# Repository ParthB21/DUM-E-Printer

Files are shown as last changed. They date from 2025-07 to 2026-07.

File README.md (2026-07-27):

# DUM-E Printer
## Demo at Open Sauce 2026
https://github.com/user-attachments/assets/50686566-a4c5-478c-9a64-cf04b380828b

## The Inspiration
We wanted to build our own 3D printer. Being die-hard Tony Stark fans, we decided to make a SCARA-style 3D printer. Introducing DUM-E Printer! It is a 5-axis robotic arm with with an extruder attached to the end to 3D print. Jokes aside, this project is really useful, becuase unlike the conventional fusion printers, the SCARA (Selective Compliance Assembly Robotic Arm) style printer is not limited by the volume of the printer bed. Morevoer, it's a lot more precise and offers greater flexibility because it has 5 axes of rotation and can directly print on top of any surface. Most importantly, SCARA-style printers are really expensive with almost no options for hobbyists. The only SCARA printers we could find were for industry and not amateurs, thus we took it as a challenge to make one and possess this cool Tony Stark-style tech.

## The Struggle
This was an extremely challenging process partly because there is no tutorial to make a SCARA 3D printer. We used a bunch of tutorials as references [in-text citation] to make a robotic arm and then figured out a way to add the 3D printer extruder to it. It's safe to say that in the past 3 weeks, 2 amateurs have become Onshape pros.

## Technical Features
We plan on using an affordable prebuilt extruder from Creality to do the actual printing. The Marlin firmware is run by an Mks Robin Nano Motherboard. For the printer's display, we have a TS35 Touchscreen. DUM-E Printer uses 5 Stepper Motors to achieve motion. There are multiple bearings in the joints to facilitate rotation.

## CAD Model
Isometric view of the assembled printer:



Top view of the assembled printer:



Front view of the assembled printer:



Side view of the assembled printer:



Exploded Diagram of the printer (to view the motors and the bearings):





Note: The blue parts are the ones that need to be 3D printed and the grey ones are the makeshift components

## Wiring Diagram


## BOM
Note: We used Amazon for some of the parts because they were either the same price or cheaper than Aliexpress. Amazon's delivery is much faster than Aliexpress so we preferred to use it if the price is same or less. All the costs beyond $350 USD will be covered by Sujay and Parth.
| Part Name | Quantity | CAD Unit Price | USD Unit Price | USD Total Cost | Link |
|---|---|---|---|---|---|
| MEISHILE 24V 25A 600W Switching Power Supply | 1 | $40.99 | $29.92 | $29.92 | [Link](https://www.amazon.ca/MEISHILE-Switching-Transformer-Converter-Amplifier/dp/B0C299DG1H) |
| Creality Ender 3 Direct Drive Extruder Upgrade Kit | 1 | $41.39 | $30.21 | $30.21 | [Link](https://www.amazon.ca/Official-Creality-Extruder-Compatible-3D/dp/B0C2CH7P54) |
| Mks Robin Nano V3.1 Eagle 32bit Control Panel TMC2209 with Screen | 1 | $52.99 | $38.68 | $38.68 | [Link](https://www.aliexpress.com/item/1005008555474559.html) |
| 22 AWG 10 m shielded wire | 1 | $9.58 | $6.99 | $6.99 | [Link](https://www.aliexpress.com/item/4000850790419.html) |
| 22 AWG 20 m silicone wire | 1 | $8.19 | $5.98 | $5.98 | [Link](https://www.aliexpress.com/item/1005006250522147.html) |
| Crimper Cable Cutter Adjustable Automatic Wire Stripper | 1 | $8.39 | $6.12 | $6.12 | [Link](https://www.aliexpress.com/item/1005007148577702.html) |
| 10PCS PCB Terminal Block Connector | 1 | $1.61 | $1.18 | $1.18 | [Link](https://www.aliexpress.com/item/1005006642865467.html) |
| 200Pcs/Box 2.54mm Pitch JST SM/Dupont Jumper Wire Connector Kit | 1 | $7.39 | $5.39 | $5.39 | [Link](https://www.aliexpress.com/item/1005003140788241.html) |
| M3 M4 M5 Bolt kit | 1 | $23.79 | $17.37 | $17.37 | [Link](https://www.aliexpress.com/item/1005008261719970.html) |
| 4x10x4 mm Bearings Set of 10 | 1 | $5.79 | $4.23 | $4.23 | [Link](https://www.aliexpress.com/item/1005007668446060.html) |
| 18x30x7 mm Bearings Set of 10 | 1 | $11.89 | $8.68 | $8.68 | [Link](https://www.aliexpress.com/item/1005009272681515.html) |
| Bore with teeth set of 6 | 1 | $8.51 | $6.21 | $6.21 | [Link](https://www.aliexpress.com/item/1005007557987612.html) |
| Belt 6mm 5m open | 1 | $5.32 | $3.88 | $3.88 | [Link](https://www.aliexpress.com/item/1005007542222728.html) |
| Bore without teeth set of 6 | 1 | $8.60 | $6.28 | $6.28 | [Link](https://www.aliexpress.com/item/1005007557987612.html) |
| Digital Caliper | 1 | $7.25 | $5.29 | $5.29 | [Link](https://www.aliexpress.com/item/1005003772701402.html) |
| Nema23 1.5 Nm stepper motors | 2 | $41.38 | $30.21 | $60.41 | [Link](https://www.aliexpress.com/item/1005007638437234.html) |
| 14:1 Gearbox + Stepper motor | 1 | $34.58 | $25.24 | $25.24 | [Link](https://www.aliexpress.com/item/1005007401751232.html) |
| 19:1 Gearbox + Stepper motor | 1 | $34.58 | $25.24 | $25.24 | [Link](https://www.aliexpress.com/item/1005007401751232.html) |
| 51:1 Gearbox + Stepper motor | 1 | $35.58 | $25.97 | $25.97 | [Link](https://www.aliexpress.com/item/1005007401751232.html) |

Total cost after taxes (in USD) = $354.03

## Citations
https://roboticworx.io/blogs/projects/build-a-5-axis-industrial-grade-robotic-arm-that-learns-how-to
https://www.drdflo.com/pages/Guides/How-to-Build-a-3D-Printer/FFF.html
https://grabcad.com/library/nema-17-40mm-stepper-motor-1
https://www.thingiverse.com/thing:2703913#google_vignette
https://ceadgroup.com/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
https://www.3dwasp.com/en/extruders-for-robotic-arm/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
https://www.youtube.com/watch?v=5toNqaGsGYs
https://www.youtube.com/watch?v=OiQKw0lZ5Rw

## Quick Notes from Authors
1. We made makeshift files and got some pre-made files for motors, gearboxes, etc. that are not going to be 3D printed as placeholders to make sure all of our CAD files are formatted properly
2. We found a template for the Marlin firmware that corresponds to the kinematics of a SCARA 3D Printer, so we plan to use that as a template and configure it based on our arm as we build it physically. 
3. Full Firmware is in the firmware branch of the repository
   - The files that are changed from the original Marlin 2.1 firmware (so far) are: Configuration.h, Configuration_adv.h, scara.h, scara.cpp, motion.cpp, servo.cpp
   - These files were modified with some help from ChatGPT and will be debugged while building and testing with hardware!

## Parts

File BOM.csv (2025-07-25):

Part Name | Quantity | CAD Unit Price | USD Unit Price | USD Total Cost | Links
MEISHILE 24V 25A 600W Switching Power Supply | 1 | $40.99 | $29.92 | $29.92 | https://www.amazon.ca/MEISHILE-Switching-Transformer-Converter-Amplifier/dp/B0C299DG1H
Creality Ender 3 Direct Drive Extruder Upgrade Kit | 1 | $41.39 | $30.21 | $30.21 | https://www.amazon.ca/Official-Creality-Extruder-Compatible-3D/dp/B0C2CH7P54
Mks Robin Nano V3.1 Eagle 32bit Control Panel TMC2209 with Screen | 1 | $52.99 | $38.68 | $38.68 | https://www.aliexpress.com/item/1005008555474559.html?mp=1
22 AWG 10 m shielded wire | 1 | $9.58 | $6.99 | $6.99 | https://www.aliexpress.com/item/4000850790419.html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
22 AWG 20 m silicone wire | 1 | $8.19 | $5.98 | $5.98 | https://www.aliexpress.com/item/1005006250522147.html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
Crimper Cable Cutter Adjustable Automatic Wire Stripper | 1 | $8.39 | $6.12 | $6.12 | https://www.aliexpress.com/item/1005007148577702.html?mp=1
10PCS PCB Terminal Block Connector | 1 | $1.61 | $1.18 | $1.18 | https://www.aliexpress.com/item/1005006642865467.html?mp=1
200Pcs/Box 2.54mm Pitch JST SM/Dupont Jumper Wire Connector Kit | 1 | $7.39 | $5.39 | $5.39 | https://www.aliexpress.com/item/1005003140788241.html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
M3 M4 M5 Bolt kit | 1 | $23.79 | $17.37 | $17.37 | https://www.aliexpress.com/item/1005008261719970.html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
4x10x4 mm Bearings Set of 10 | 1 | $5.79 | $4.23 | $4.23 | https://www.aliexpress.com/item/1005007668446060.html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
18x30x7 mm Bearings Set of 10 | 1 | $11.89 | $8.68 | $8.68 | https://www.aliexpress.com/item/1005009272681515.html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
Bore with teeth set of 6 | 1 | $8.51 | $6.21 | $6.21 | https://www.aliexpress.com/item/1005007557987612.html?mp=1
Belt 6mm 5m open | 1 | $5.32 | $3.88 | $3.88 | https://www.aliexpress.com/item/1005007542222728.html?mp=1
Bore without teeth set of 6 | 1 | $8.60 | $6.28 | $6.28 | https://www.aliexpress.com/item/1005007557987612.html?mp=1
Digital Caliper | 1 | $7.25 | $5.29 | $5.29 | https://www.aliexpress.com/item/1005003772701402.html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
Nema23 1.5 Nm stepper motors | 2 | $41.38 | $30.21 | $60.41 | https://www.aliexpress.com/item/1005007638437234.html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
14:1 Gearbox + Stepper motor | 1 | $34.58 | $25.24 | $25.24 | https://www.aliexpress.com/item/1005007401751232.html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
19:1 Gearbox + Stepper motor | 1 | $34.58 | $25.24 | $25.24 | https://www.aliexpress.com/item/1005007401751232.html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
51:1 Gearbox + Stepper motor | 1 | $35.58 | $25.97 | $25.97 | https://www.aliexpress.com/item/1005007401751232.html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
 |  | $387.80 | $283.09 | $313.30
 |  |  | Shipping USD | $0.00
 |  |  | Total USD (including tax) | $354.03

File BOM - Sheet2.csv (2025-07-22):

Part Name | Quantity | CAD Unit Price | USD Unit Price | USD Total Cost | Links | Notes
MEISHILE 24V 25A 600W Switching Power Supply | 1 | $42.99 | $31.38 | $31.38 | https://www.amazon.ca/MEISHILE-Switching-Transformer-Converter-Amplifier/dp/B0C299DG1H
ELEGOO PLA Filament 1.75mm Black 1KG | 1 | $23.99 | $17.51 | $17.51 | https://www.amazon.ca/ELEGOO-Filament-Dimensional-Accuracy-Compatible/dp/B0BM4F65SL
Creality Ender 3 Direct Drive Extruder Upgrade Kit | 1 | $41.39 | $30.21 | $30.21 | https://www.amazon.ca/Official-Creality-Extruder-Compatible-3D/dp/B0C2CH7P54
Mks Robin Nano V3.1 Eagle 32bit Control Panel TMC2209 with Screen | 1 | $52.99 | $38.68 | $38.68 | https://www.aliexpress.com/item/1005008555474559.html?mp=1
Heat Resistant Soft Silicone Wire 5 Colors in A Box Kit 30AWG 100 meters | 1 | $14.68 | $10.72 | $10.72 | https://www.aliexpress.com/item/1005006350734418.html?mp=1
Crimper Cable Cutter Adjustable Automatic Wire Stripper | 1 | $8.39 | $6.12 | $6.12 | https://www.aliexpress.com/item/1005007148577702.html?mp=1
10PCS PCB Terminal Block Connector | 1 | $1.61 | $1.18 | $1.18 | https://www.aliexpress.com/item/1005006642865467.html?mp=1
200Pcs/Box 2.54mm Pitch JST SM/Dupont Jumper Wire Connector Kit | 1 | $7.39 | $5.39 | $5.39 | https://www.aliexpress.com/item/1005003140788241.html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
M4 Bolt Kit | 1 | $8.59 | $6.27 | $6.27 | https://www.aliexpress.com/item/1005008261719970.html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
M3 Bolt Kit | 1 | $8.80 | $6.42 | $6.42 | https://www.aliexpress.com/item/1005007552265164.html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
4x10x4 mm Bearings Set of 10 | 1 | $5.79 | $4.23 | $4.23 | https://www.aliexpress.com/item/1005007668446060.html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
18x30x7 mm Bearings Set of 10 | 1 | $11.89 | $8.68 | $8.68 | https://www.aliexpress.com/item/1005009272681515.html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 | This link is for 5*10*4 mm bearings, should I change it to 4*10*4
Bore with teeth set of 6 | 1 | $8.51 | $6.21 | $6.21 | https://www.aliexpress.com/item/1005007557987612.html?mp=1
Belt 6mm 5m open | 1 | $5.32 | $3.88 | $3.88 | https://www.aliexpress.com/item/1005007542222728.html?mp=1 | The link is wrong, this is not a belt
Bore without teeth set of 6 | 1 | $8.60 | $6.28 | $6.28 | https://www.aliexpress.com/item/1005007557987612.html?mp=1
Digital Caliper | 1 | $7.25 | $5.29 | $5.29 | https://www.aliexpress.com/item/1005003772701402.html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
5.18:1 Gearbox + Stepper motor | 2 | $33.58 | $24.51 | $49.03 | https://www.aliexpress.com/item/1005007401751232.html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
14:1 Gearbox + Stepper motor | 1 | $34.58 | $25.24 | $25.24 | https://www.aliexpress.com/item/1005007401751232.html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
19:1 Gearbox + Stepper motor | 1 | $34.58 | $25.24 | $25.24 | https://www.aliexpress.com/item/1005007401751232.html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
51:1 Gearbox + Stepper motor | 1 | $35.58 | $25.97 | $25.97 | https://www.aliexpress.com/item/1005007401751232.html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
 |  | $396.50 | $289.45 | $313.96
 |  |  | Shipping USD | $0.00
 |  |  | Total USD | $313.96

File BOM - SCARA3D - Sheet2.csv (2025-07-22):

Part Name | Quantity | CAD Unit Price | USD Unit Price | USD Total Cost | Links | Notes
MEISHILE 24V 25A 600W Switching Power Supply | 1 | $42.99 | $31.38 | $31.38 | MEISHILE 24V 25A 600W Switching Power Supply Adapter AC to DC Transformer Converter for LED Driver Strip Light Lamp, Amplifier, Machine, 120V 110V to 24Volt 3A 4A 5A 8A 10A 15A 20Amp : Amazon.ca: Tools & Home Improvement
ELEGOO PLA Filament 1.75mm Black 1KG | 1 | $23.99 | $17.51 | $17.51 | ELEGOO PLA Filament 1.75mm Black 1KG,3D Printer Filament Dimensional Accuracy +/- 0.02mm,1kg Cardboard Spool(2.2lbs) 3D Printing Filament Fits for Most FDM 3D Printers : Amazon.ca: Industrial & Scientific
Creality Ender 3 Direct Drive Extruder Upgrade Kit | 1 | $41.39 | $30.21 | $30.21 | Official Creality Ender 3 Direct Drive Extruder Upgrade Kit with 42-40 Stepper Motor Hotend Kit, Support Flexible TPU Filament, Compatible with Ender 3 Pro/Ender 3 V2 3D Printer : Amazon.ca: Industrial & Scientific
Mks Robin Nano V3.1 Eagle 32bit Control Panel TMC2209 with Screen | 1 | $52.99 | $38.68 | $38.68 | Makerbase Mks Robin Nano V3.1 Eagle 32bit Control Panel TMC2209 Motor Drive WIFI 3D Touch Screen 3D Printer Parts Motherboard - AliExpress
Heat Resistant Soft Silicone Wire 5 Colors in A Box Kit 30AWG 100 meters | 1 | $14.68 | $10.72 | $10.72 | Super Soft Copper Wire Box (5 Colors Mix Kit) Heat Resistant Flexible Silicone 30/28/26/24/22/20AWG Electric Tinned Copper Cable - AliExpress |  | Shipping USD | $0.00
Crimper Cable Cutter Adjustable Automatic Wire Stripper | 1 | $8.39 | $6.12 | $6.12 | Crimper Cable Cutter Adjustable Automatic Wire Stripper Multifunctional Stripping Crimping Pliers Terminal Hand Tool - AliExpress |  | Total USD | $313.96
10PCS PCB Terminal Block Connector | 1 | $1.61 | $1.18 | $1.18 | 10/50PCS PCB Terminal Block Connector Pitch 5.0mm KF301 Straight Pin 2P 3P Screw PCB Terminal Blocks Connector Assortment Kit - AliExpress 13
200Pcs/Box 2.54mm Pitch JST SM/Dupont Jumper Wire Connector Kit | 1 | $7.39 | $5.39 | $5.39 | 200Pcs/Box 2.54mm Pitch JST SM/Dupont Jumper Wire Connector Kit 2/3/4/5Pin Male/Female Housing Pin Header Crimp Terminal Adapter - AliExpress
M4 Bolt Kit | 1 | $8.59 | $6.27 | $6.27 | M4 M5 M6 Metric Bolt Kit Stainless Steel Assortment Set with Hex Head Bolts Nuts Flat & Lock Washer for DIY Home Industrial Use - AliExpress
M3 Bolt Kit | 1 | $8.80 | $6.42 | $6.42 | 320/640pcs M3 Screw Stainless Steel Hexagon Hex Socket Screws Bolt Nuts Set Round Flat Cap Head Bolt Washer Assortment Kit - AliExpress
4x10x4 mm Bearings Set of 10 | 1 | $5.79 | $4.23 | $4.23 | 10/50pcs Small Bearings 2mm 3mm 4mm 5mm 6mm 7mm 8mm 9mm 10mm Bore 3x7x3 5x10x4 5x11x4 8x22x7 10x15x4 mm Miniature Bearing - AliExpress
18x30x7 mm Bearings Set of 10 | 1 | $11.89 | $8.68 | $8.68 | 10pcs 16100 12268 15267 15268 16287 163010 18287 18307 20307 24377 25376 2RS RS Bearings Rubber Sealed Bicycle Ball Bearing - AliExpress | This link is for 5*10*4 mm bearings, should I change it to 4*10*4
Bore with teeth set of 6 | 1 | $8.51 | $6.21 | $6.21 | 2/4/6pcs GT2 Idler Timing Pulley 16/20 Tooth Wheel Bore 3/5mm Aluminium Gear Teeth Width 6/10mm For Ender 3 CR10 Printer Reprap - AliExpress
Belt 6mm 5m open | 1 | $5.32 | $3.88 | $3.88 | 5/10M GT2 Belt PU Steel Wire Timing Pulley GT2-6mm Open Synchronous Rubber Belts Width 6mm for DIY CNC 3D Printer Parts - AliExpress | The link is wrong, this is not a belt
Bore without teeth set of 6 | 1 | $8.60 | $6.28 | $6.28 | 2/4/6pcs GT2 Idler Timing Pulley 16/20 Tooth Wheel Bore 3/5mm Aluminium Gear Teeth Width 6/10mm For Ender 3 CR10 Printer Reprap - AliExpress
Digital Caliper | 1 | $7.25 | $5.29 | $5.29 | 150mm 100mm Electronic Digital Caliper Carbon Fiber Dial Vernier Caliper Gauge Micrometer Measuring Tool Digital Ruler - AliExpress
5.18:1 Gearbox + Stepper motor | 2 | $33.58 | $24.51 | $49.03 | 1Pc 42BYG stepper motor 40mm body length with 3.71:1 -139:1 ratio NEMA17 planetary gear stepping motor with gearbox - AliExpress
14:1 Gearbox + Stepper motor | 1 | $34.58 | $25.24 | $25.24 | 1Pc 42BYG stepper motor 40mm body length with 3.71:1 -139:1 ratio NEMA17 planetary gear stepping motor with gearbox - AliExpress
19:1 Gearbox + Stepper motor | 1 | $34.58 | $25.24 | $25.24 | 1Pc 42BYG stepper motor 40mm body length with 3.71:1 -139:1 ratio NEMA17 planetary gear stepping motor with gearbox - AliExpress
51:1 Gearbox + Stepper motor | 1 | $35.58 | $25.97 | $25.97 | 1Pc 42BYG stepper motor 40mm body length with 3.71:1 -139:1 ratio NEMA17 planetary gear stepping motor with gearbox - AliExpress
 |  |  | $0.00 | $0.00
 |  | $396.50 | $289.45 | $313.96

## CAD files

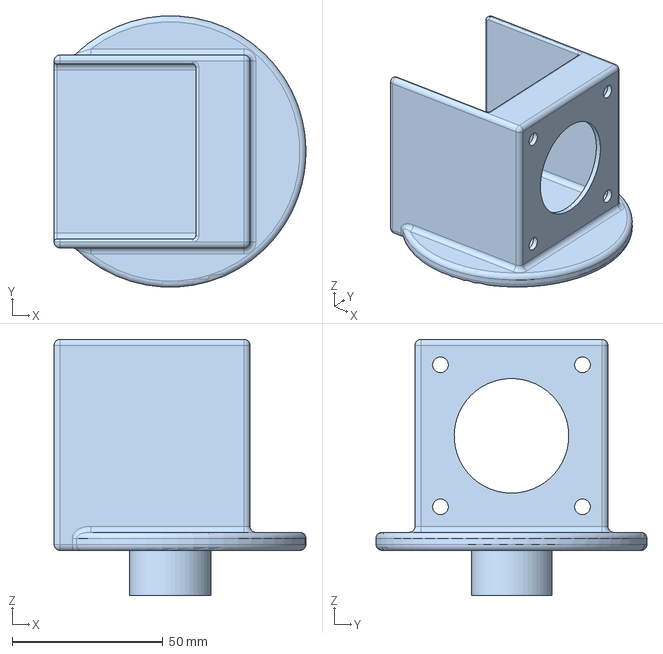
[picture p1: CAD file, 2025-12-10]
CAD/Wrist Pitch mount.step
83.5 x 89.9 x 85.0 mm

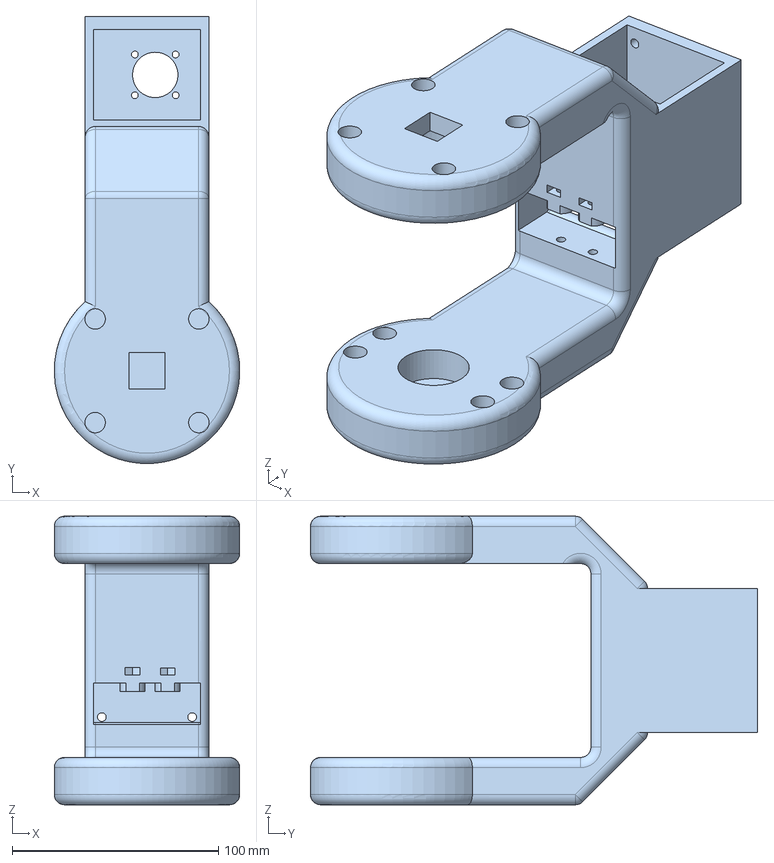
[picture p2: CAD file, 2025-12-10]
CAD/J1.step
90.0 x 216.9 x 140.0 mm

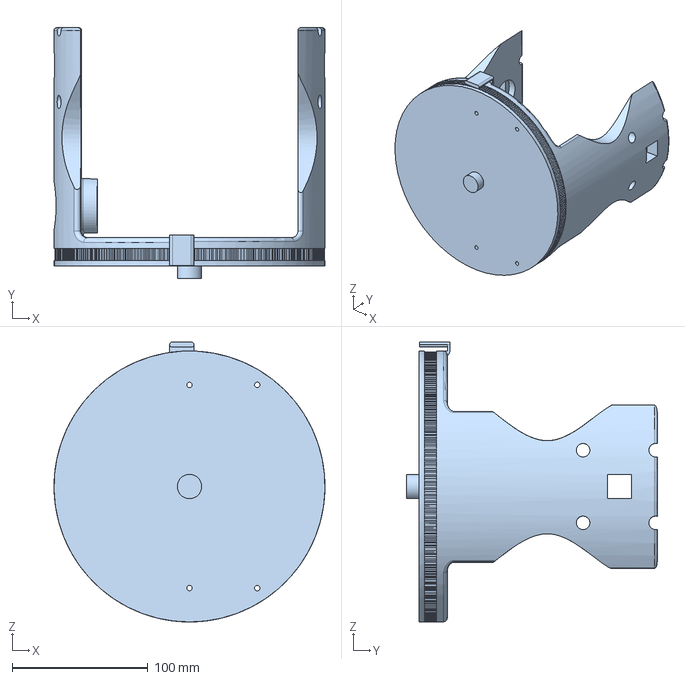
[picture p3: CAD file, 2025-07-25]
CAD/Base.step
200.0 x 185.0 x 206.6 mm

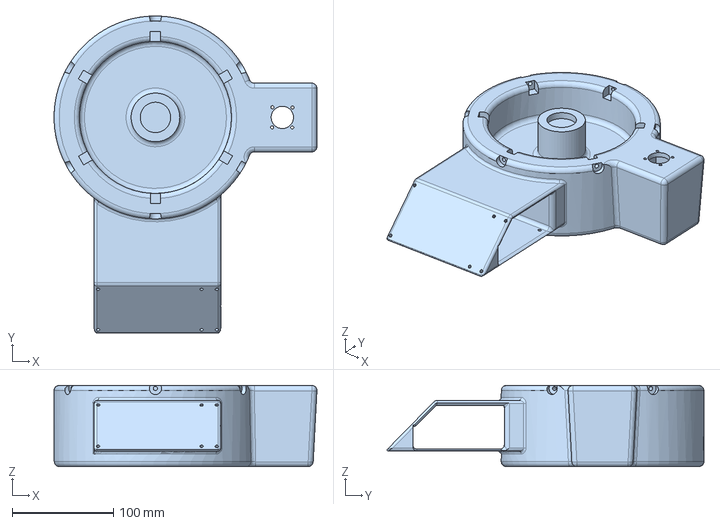
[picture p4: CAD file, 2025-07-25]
CAD/Base Plate.step
259.3 x 312.6 x 80.0 mm

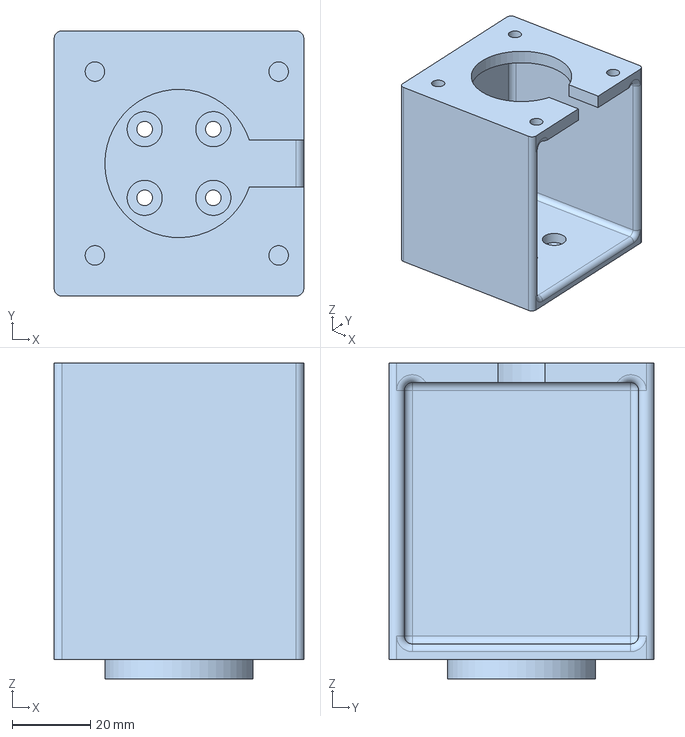
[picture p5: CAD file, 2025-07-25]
CAD/Wrist Roll.step
64.0 x 68.0 x 81.0 mm

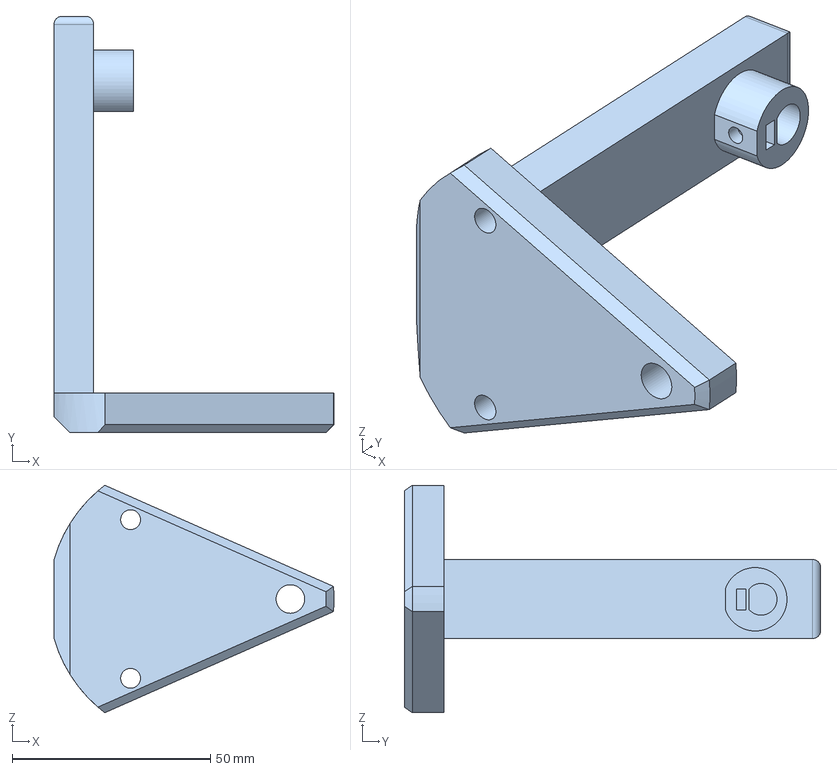
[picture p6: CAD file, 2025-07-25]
CAD/Wrist Pitch End.step
70.6 x 105.0 x 57.4 mm

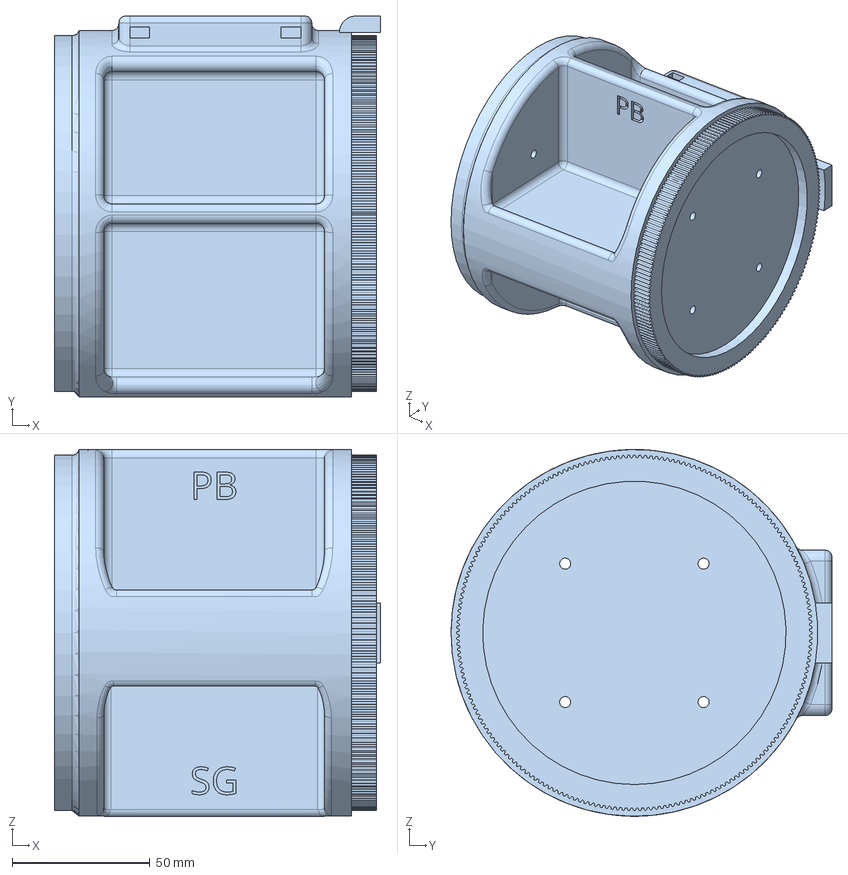
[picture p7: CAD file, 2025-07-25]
CAD/J1 Base.step
118.4 x 138.2 x 133.1 mm

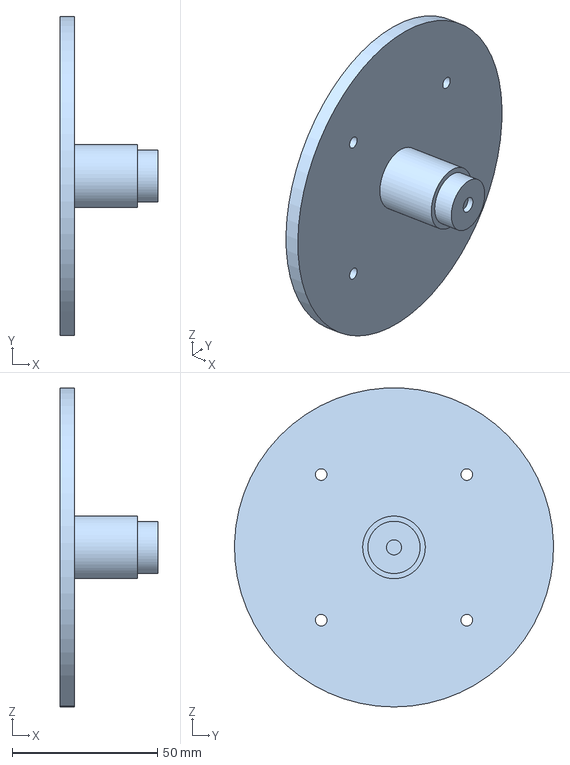
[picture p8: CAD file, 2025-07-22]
CAD/J1 Base Mount.step
33.7 x 110.0 x 109.9 mm

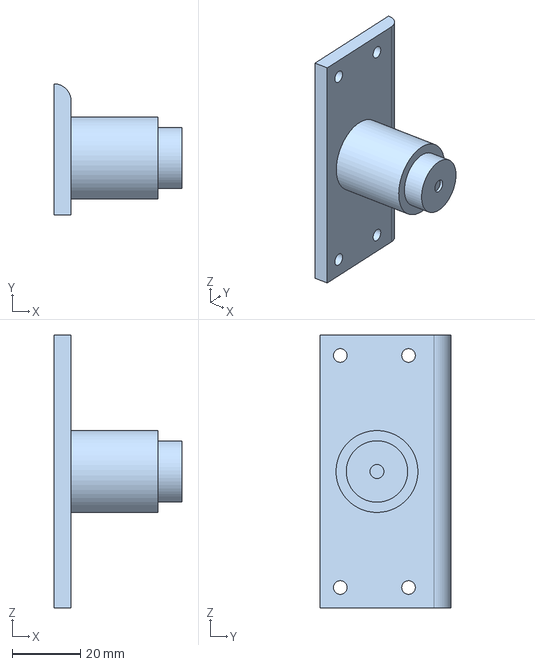
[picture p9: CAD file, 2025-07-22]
CAD/J2 Mount - no teeth.step
37.5 x 38.5 x 80.0 mm

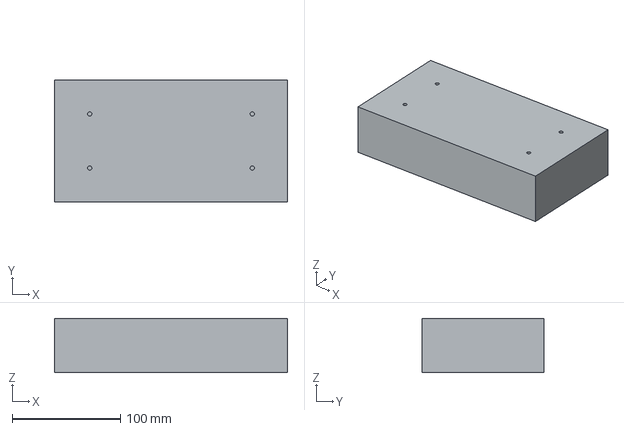
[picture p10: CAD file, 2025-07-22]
CAD/Makeshift power supply.step
215.0 x 112.5 x 50.0 mm

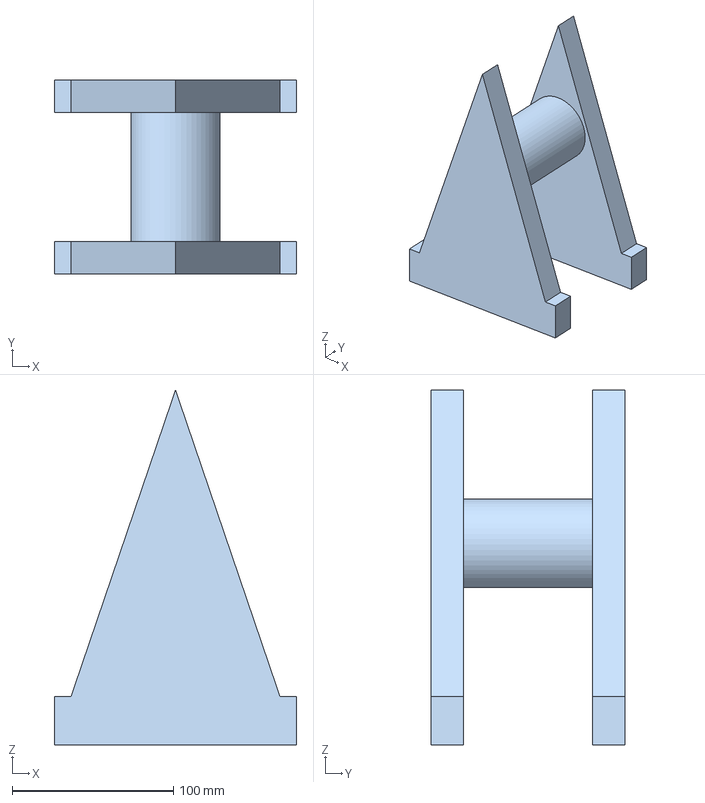
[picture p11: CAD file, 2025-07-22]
CAD/Spool stand.step
150.0 x 120.0 x 220.0 mm

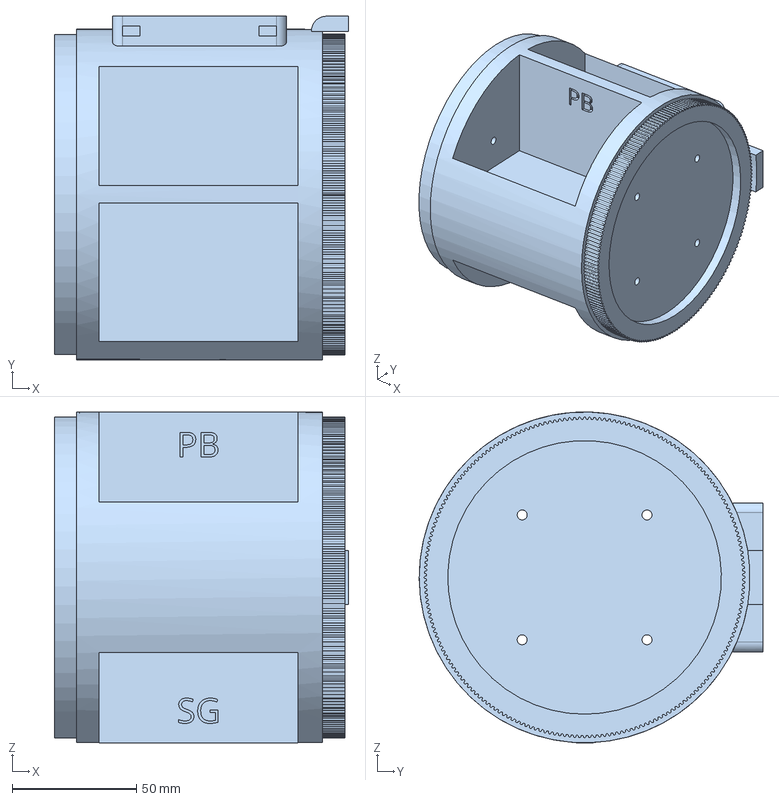
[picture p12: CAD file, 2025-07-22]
CAD/J1 Base New.step
118.4 x 138.2 x 133.1 mm

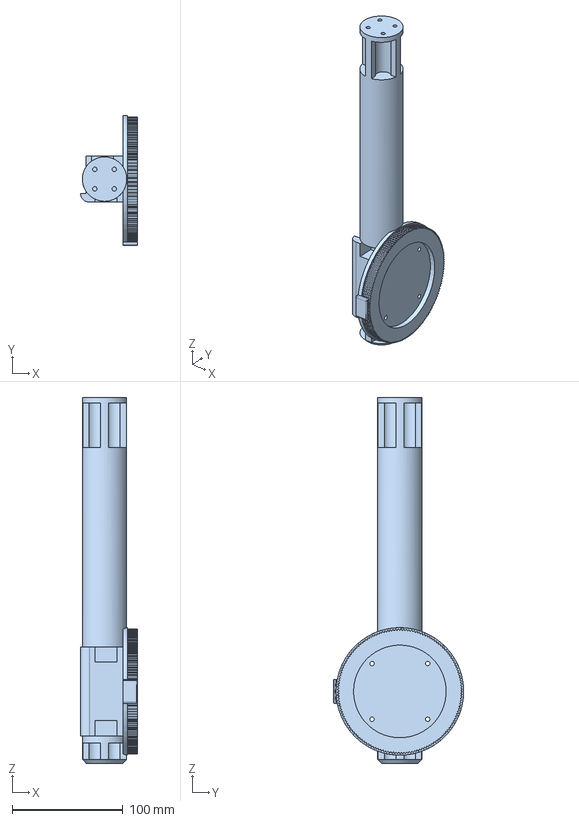
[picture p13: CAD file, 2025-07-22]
CAD/J2.step
51.5 x 117.5 x 330.0 mm

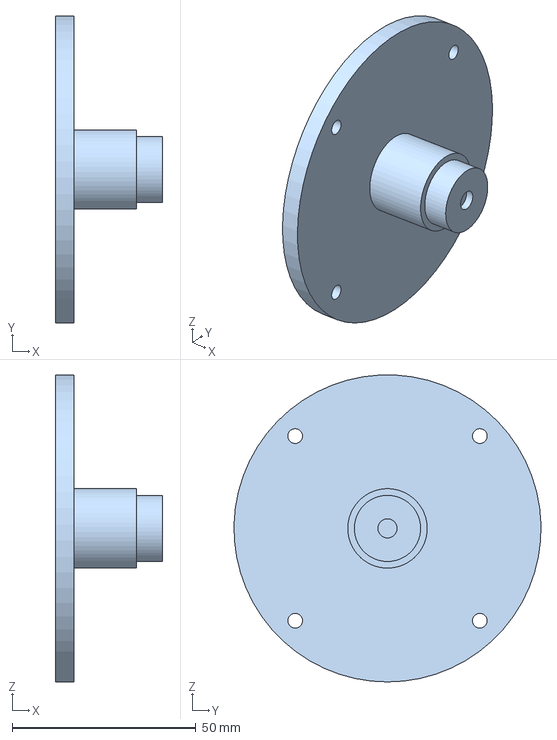
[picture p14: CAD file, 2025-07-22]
CAD/J2 Mount.step
29.0 x 83.5 x 83.4 mm

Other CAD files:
CAD/Wrist Pitch Motor Horn.step
CAD/Extruder.step

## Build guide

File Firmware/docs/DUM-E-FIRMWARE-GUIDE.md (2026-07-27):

# DUM-E — Step-by-step bring-up

Follow the steps **in order**. Do not skip ahead to heating or homing until the earlier steps pass.

**What this robot can do right now:** move four joints (yaw, shoulder pitch, wrist pitch, wrist roll) and run the extruder. It is **not** a normal Cartesian printer yet. When you send `G1 X10`, that means “move shoulder yaw by about 10 degrees,” **not** “move 10 mm in X.”

---

## Quick map (keep this nearby)

| Motor plug on board | What it moves | Command letter |
| --- | --- | --- |
| **X** | Shoulder yaw | `X` |
| **Y** | Wrist pitch | `Y` |
| **Z** (Z0 and Z1 = same motor) | Shoulder pitch | `Z` |
| **E0** | Wrist roll | `A` |
| **E1** | Filament extruder | `E` |

---

# STEP 1 — Safety before anything moves

1. Put the arm somewhere it cannot hit the table or itself.
2. Keep your hand on the **24 V power switch** so you can cut power instantly.
3. Prefer the arm **supported** or joints free for the first tiny moves.
4. Do **not** heat the hotend in this step.

**You’re done with Step 1 when:** you can kill power in one second.

---

# STEP 2 — Build the firmware (if you haven’t)

1. Open the folder `Marlin-2.1.2.6` in Cursor / VS Code.
2. Open **Marlin Auto Build** (or PlatformIO).
3. Click **Build** on environment `**mks_robin_nano_v3_1`**.
4. Wait until it says **SUCCESS** (warnings are OK).

**You should see:** green success, file created under  
`.pio/build/mks_robin_nano_v3_1/Robin_nano_v3.bin`

**If it fails:** copy the red errors and ask for help (don’t continue).

**You’re done with Step 2 when:** the `.bin` file exists.

---

# STEP 3 — Put firmware on SD or USB stick

1. Format the SD card or USB stick as **FAT32**.
2. Open the folder:
  `Marlin-2.1.2.6/.pio/build/mks_robin_nano_v3_1/`
3. Copy **both** of these to the **root** of the stick (not in a subfolder):
  - `Robin_nano_v3.bin` (exact name)
  - the whole folder named `assets`
4. Eject the stick safely from the PC.

**You’re done with Step 3 when:** stick root contains `Robin_nano_v3.bin` and `assets/`.

---

# STEP 4 — Flash the board

1. Insert the SD card **or** plug the USB stick into the board’s **USB-A host** port (big flat USB, not the tiny USB-to-PC).
2. Connect the **24 V power supply** and turn it on.
3. Watch the TS35 screen.

**You should see:**

1. An update / progress screen, then
2. The board restarts into the Marlin UI.

**Also check the stick afterward:** `Robin_nano_v3.bin` may be renamed to something like `Robin_nano_v3.CUR` — that means flash worked.

**If the screen stays blank:**

- Confirm `assets` was copied
- Confirm 24 V is on
- Reseat the TS35 cable
- Try a different FAT32 SD card

**You’re done with Step 4 when:** the touchscreen shows a normal Marlin / MKS main screen and the machine name is **DUM-E** (or similar).

---

# STEP 5 — Open serial on the PC (PlatformIO)

This is how you type test commands.

1. Leave **24 V on**.
2. Plug the board’s **small USB** (to PC) into your computer.
3. In Cursor / VS Code with the Marlin project open:
  - PlatformIO sidebar → **PROJECT TASKS** → `mks_robin_nano_v3_1` → **General** → **Monitor**  
  - or click the PlatformIO **serial plug** icon
4. Baud rate is already **115200**.

**You should see:** a terminal window that connects to a COM port (may show `echo:` or be quiet until you type).

**If it says port busy / can’t open:**

- Close Pronterface or any other serial program
- Unplug/replug USB
- Try again

**You’re done with Step 5 when:** the serial monitor stays open without errors.

---

# STEP 6 — Smoke test (no motor moves yet)

In the serial monitor, type each line and press Enter.

### 6.1 — Is firmware alive?

Type:

```text
M115
```

**You should see:** text mentioning Marlin and the board.

### 6.2 — Are temperatures sane?

Type:

```text
M105
```

**You should see:** a hotend temperature near room temperature (e.g. 20–30 °C).  
**Do not** send heat commands yet.

### 6.3 — Can the drivers talk over UART?

Type:

```text
M122
```

**You should see:** driver reports for the axes.  
**Bad sign:** lines like `Unable to communicate` for X/Y/Z/E — stop and fix wiring/config before moving motors.

**You’re done with Step 6 when:** `M115`, `M105`, and `M122` all look healthy.

---

# STEP 7 — Tiny joint moves (direction test)

Still in serial monitor. Move **one joint at a time**. Watch the robot. Be ready to kill power.

First put Marlin in relative mode:

```text
G91
```

### 7.1 — Shoulder yaw (plug X)

```text
G1 X5 F20
```

**You should see:** shoulder yaw move a little.

- Wrong way? Note it as “X inverted” (we’ll fix after).
- No move / skipping? Kill power; note which motor.

### 7.2 — Wrist pitch (plug Y)

```text
G1 Y5 F20
```

### 7.3 — Shoulder pitch (plug Z)

```text
G1 Z5 F20
```

### 7.4 — Wrist roll (plug E0, commanded as A)

```text
G1 A5 F20
```

### 7.5 — Fix wrong directions (if needed)

If a joint moved the wrong way:

1. Open `Marlin/Configuration.h`
2. Find `INVERT_X_DIR`, `INVERT_Y_DIR`, `INVERT_Z_DIR`, `INVERT_I_DIR` (I = wrist roll / A)
3. Change `false` ↔ `true` for that axis only
4. Rebuild (Step 2), reflash (Steps 3–4), retest that one joint

**You’re done with Step 7 when:** each joint moves in a direction you agree is “positive.”

### If motors do NOT move (do this checklist)

Send these **one line at a time** and watch both the reply **and** the motors:

```text
M115
M122
M211 S0
M17
G92 X0 Y0 Z0 A0
G91
G1 X30 F30
```

What each does:

| Command | Purpose |
| --- | --- |
| `M122` | Confirms TMC drivers answer (if “Unable to communicate”, motors won’t work until UART/drivers are fixed) |
| `M211 S0` | Turn **off** soft endstops (they can silently block moves) |
| `M17` | **Enable** steppers (motors should feel locked / harder to turn by hand) |
| `G92 ...` | Set current joint angles to 0 so limits don’t block you |
| `G1 X30 F30` | Bigger, easier-to-see yaw move |

**Check with your hand (power on, after `M17`):**

1. Try to twist the **X** motor shaft / coupling gently.
2. If it feels **free / floppy** → steppers are not enabled or not powered.
3. If it feels **locked** but still doesn’t move on `G1` → note the serial reply and tell me what it said.

**Also confirm physically:**

- 24 V PSU is on (USB alone is not enough for motors)
- Motor plugs are fully seated in **X / Y / Z / E0 / E1**
- You’re testing the motor that matches the command (`X` = shoulder yaw plug)

**Common serial replies:**

| You see | Meaning |
| --- | --- |
| `ok` and motor locked but no motion | Tell me; may be current / wiring / wrong plug |
| `echo:Unknown command: "G1 A..."` | Use `G1 I5 F20` instead, or rebuild with I-axis enabled |
| Endstop / homing / “must home” style message | Paste the exact text |
| `Unable to communicate` in `M122` | Fix TMC UART first — motion won’t work |

**Reset settings if an old EEPROM is fighting you:**

```text
M502
M500
M17
G92 X0 Y0 Z0 A0
G91
G1 X30 F30
```

---

# STEP 8 — Calibrate steps (angle accuracy)

You don’t need exact belt ratios. Measure instead.

Example for **X** (do the same idea for Y, Z, A):

1. Mark the joint with tape/pen so you can see rotation.
2. Send:

```text
G91
G1 X90 F30
```

1. Measure how many degrees it **actually** moved (protractor / careful estimate is fine for now).
2. Compute:

`new_steps = old_steps × (90 / measured_degrees)`

Starting values already in firmware:

- X ≈ 124.44  
- Y ≈ 8.89  
- Z ≈ 453.33  
- A ≈ 8.89

1. Apply temporarily over serial (example if new X steps were 200):

```text
M92 X200
M500
```

Or edit `DEFAULT_AXIS_STEPS_PER_UNIT` in `Configuration.h` and rebuild later.

**You’re done with Step 8 when:** commanding ~90° on each joint gets roughly 90° of real motion.

---

# STEP 9 — Wire the 4 endstops (later; skip until motors feel good)

Do this **after** Steps 6–8 feel safe.

### 9.1 — Remove DIAG jumpers

On the Robin Nano, **remove the DIAG jumpers** (needed because you use real endstops, not sensorless).

### 9.2 — Plug endstops

| Board plug | Joint |
| --- | --- |
| **X-** | Shoulder yaw |
| **Z-** | Shoulder pitch |
| **Y-** | Wrist pitch |
| **Z+** | Wrist roll |

Do **not** put an endstop on the extruder.

### 9.3 — Test with M119

```text
M119
```

1. Read the report.
2. Block / unblock one sensor at a time.
3. That line should switch between `open` and `TRIGGERED`.

If a sensor is always wrong / inverted: flip that axis’s `*_ENDSTOP_INVERTING` in `Configuration.h`, rebuild, reflash, retest.

### 9.4 — Homing (only after M119 looks right)

```text
G28
```

Watch carefully; kill power if a joint drives into a hard stop without triggering.

**You’re done with Step 9 when:** all four endstops toggle correctly and a careful `G28` works.

---

# STEP 10 — Hotend (only after motion is trusted)

1. Confirm heater + thermistor wired correctly.
2. Heat:

```text
M104 S200
M105
```

Temp should rise toward 200 °C. If it doesn’t, or errors appear — kill power / stop heating.

1. When stable, optional PID tune:

```text
M303 E0 S200 C8
M500
```

1. Extrusion test (hot enough first): mark filament, then:

```text
G1 E10 F100
```

**You’re done with Step 10 when:** hotend heats controllably and extruder feeds filament.

---

# STEP 11 — What “done for now” means

You are in good shape for early DUM-E testing when:

- [ ] Screen boots to DUM-E UI  
- [ ] `M115` / `M105` / `M122` work  
- [ ] All four joints jog safely with correct directions  
- [ ] Steps are roughly calibrated  
- [ ] (Optional) Endstops + homing work  
- [ ] (Optional) Hotend heats and extrudes  

You are **not** ready to slice a normal STL and print it yet. That needs elbow hardware + real arm kinematics later.

---

## Common serial commands cheat sheet

| Command | Meaning |
| --- | --- |
| `M115` | Firmware identity |
| `M105` | Temperatures |
| `M122` | TMC driver status |
| `M119` | Endstop status |
| `G91` | Relative moves |
| `G90` | Absolute moves |
| `G1 X5 F20` | Move yaw ~5° slowly |
| `G1 A5 F20` | Move wrist roll ~5° slowly |
| `G28` | Home (only after endstops work) |
| `M18` | Disable steppers (motors free)  |
| `M17` | Enable steppers |

---

## Where things live in the repo

| File | What you’d edit |
| --- | --- |
| `Marlin/Configuration.h` | Directions (`INVERT_*`), steps, endstop invert, board/UI |
| `Marlin/Configuration_adv.h` | Motor currents, homing bump |
| `platformio.ini` | Build env `mks_robin_nano_v3_1` |

---

## If you’re stuck

Say which **Step number** you’re on, and paste either:

- what you see on the screen, or  
- the serial reply to the last command you sent.

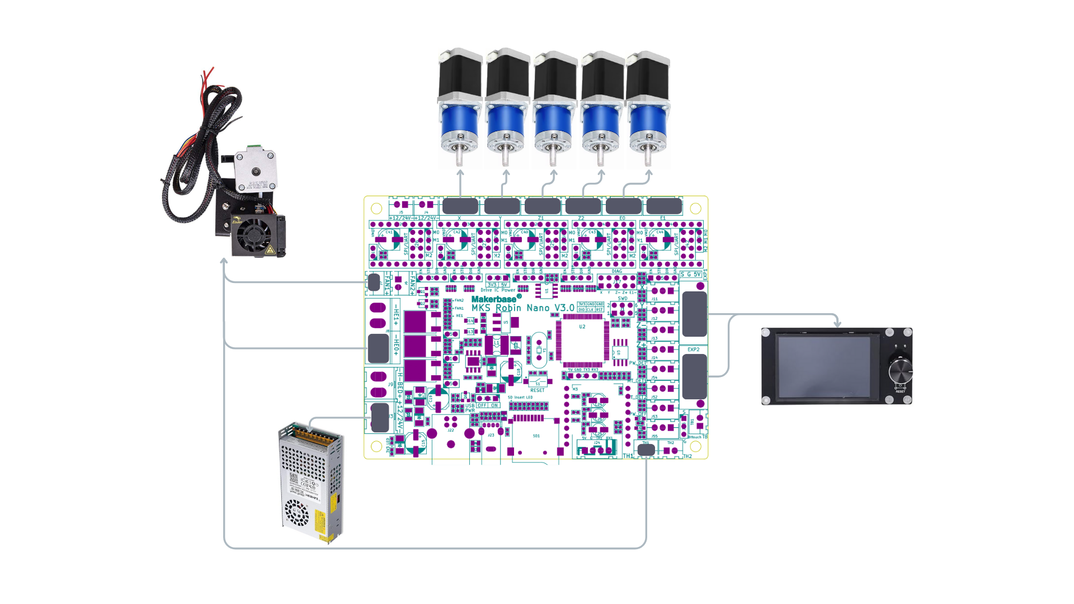
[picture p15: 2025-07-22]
Wiring Diagram.png

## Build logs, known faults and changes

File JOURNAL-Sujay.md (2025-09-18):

---
title: DUM-E Printer - Sujay's Journal
authors: Sujay Golla
description: A 5-axis robotic arm that can 3D Print (SCARA 3D printer) 
started_working: 2025-07-01
total_hrs_submitted: 89
total_hrs_worked: 106
---
(Note: we modified a few things after submission and updated the CAD files and Readme which is why the submitted hours and total hours do not match)

# July 1: Brainstorming
## Hours Spent: 5
We decided to build a SCARA 3D printer from various different options. We discussed what features we want our 3D printer to have and looked for inspiration from other 3D Printers.

Some features I wanted to include:
- 5 DOF Arm with a 3D printed case
- Some configuration of a pre-built extruder

# July 3: Working on BOM
## Hours Spent: 3
I decided to start working on the BOM to get a better idea of the dimensions of the parts and electronics to start working on the wiring diagrams and the CAD. I referred to the following tutorials to get a better sense of how our printer will work:
- https://www.drdflo.com/pages/Guides/How-to-Build-a-3D-Printer/FFF.html
- https://roboticworx.io/blogs/projects/build-a-5-axis-industrial-grade-robotic-arm-that-learns-how-to

Then, I came up with a rough idea for the BOM:
- Servos or stepper motors????
- Belt, pulley wheels, bearings, wires, jumper wires
- Motherboard (preferably with Marlin 2.0)
- Extruder stuff
- Power supply
- Filament (for the 3D printed shell of the arm)

I also started gathering links for some of the major expenses and parts for a proper BOM:


We plan to finish the BOM while working on wiring diagrams and CAD simultaneously to make sure we include all of the components needed to make the project.

# July 7: Working on BOM and the wiring diagram
## Hours Spent: 8
Today, I worked on finalizing our BOM by sourcing parts from AliExpress and Amazon (wherever they are cheaper) by referencing the same tutorials, picking all the smaller items like wires and tools. AliExpress' welcome offer helped cut down costs, but some parts require paid shipping, which might take away the benefit of buying for cheap from AliExpress. Finding the cheapest options, understanding the purpose and optimizing the models for different parts took a lot of time, especially as we are new to hardware projects. For now, our BOM looks like:


Picking the stepper motors and the gearboxes was the most tiring task of all. I had to estimate lengths and weights to calculate torques on the arm to pick the right gearboxes:


I also made a wiring diagram for the printer motherboard, but since I don't have much experience with professional tools, I made a comprehensive diagram on Canva:


With all of the specifications for the parts, we can finally work on the CAD starting tomorrow!

# July 10-15: Learning Onshape
## Hours Spent: 2

I tried to spend this time learning Onshape, but due to other commitments, I wasn't able to spend much time on it.

# July 16: 3D Printed Sections list + CAD
## Hours Spent: 12

Today, I came up with a list of parts that need to be designed on Onshape while delving deeper into the structure and function of every component of the robotic arm that I took inspiration from. After hours of narrowing things down and coming up with different ideas, I made an ordered list from the shoulder/base of the arm to the tip:


I hope that this table will help us stay organized and not procrastinate on the CAD any further :D
We decided to split the work and make each person start from different ends of the list. I started working from the last part:

The last part looks like this:


I plan to spend more time and finish the CAD asap. While we are inspired by the tutorial, we are referencing it for the dimensions of bolts and general dimensions of the arm, just so we can go off of something. The actual arm will look different and of course, the functionality will be much more complex and unique. 

# July 17: CAD + BOM
## Hours Spent: 10

Today, I made progress on the CAD from the wrist of the arm. I spent a lot of time working on the wrong idea of finding a way to install the rollers from the extruder kit, and after designing the next part for a few hours, I realized we could just directly connect it to the "Wrist Pitch End." Then, I fixed the CAD and realized the next part needed precise details about the motor. However, I also realized the delivery date for AliExpress is going past the event, so I had to find new motors and gearboxes, which I did luckily! It also saved us in AliExpress shipping costs so that was a bonus! So, the part from the tip of the arm looks like this now: 


The part that I also made on progress looks like this (just need to design a section to fit the motor + gearbox and ensure it connects to the next part, which should hopefully be quick for tomorrow:


The BOM looks like this now:


Tomorrow, hopefully I can make more progress from the lessons learned today ToT

# July 18: CAD
## Hours Spent: 11

We continued to make progress in both directions. From the wrist end of the arm, I modified and finished on a couple of parts, finishing the wrist section of the arm, and made progress on the forearm. 







Just plan to continue making progress from both ends!

# July 19: CAD
## Hours Spent: 12

We made a lot of progress in the CAD today, possibly over 70% done the entire arm. From the wrist end of the arm, I finished the entirety of J2 and worked on 70% of J1. A lot of parts for J1 are going to be similar to J2, so I hope this will be finished even quicker. The biggest challenge was trying to find a way to create ridges for our timing belts. This took a lot of trial and error, but after hours of work, I figured it out and made it for the J2 components. Here are some parts I worked on and finished today: 





Tomorrow, we plan to finish the CAD and submit the proposal!

# July 20: CAD
## Hours Spent: 14

I continued designing from the back and finished up to J1 Base. Then we started assembling all the parts in the assembly file. There were so many errors and dimensions issues that we had to go back and redo a bunch of parts. The entire process took way longer than we expected and we had to pull an all-nighter. While Parth worked on fixing the dimensions, I worked on assembling things and arranging them in the assembly file. Unfortunately we could not submit because we still had a bunch of stuff left to do. We must submit this tomorrow!



# July 21: CAD
## Hours Spent: 12

We finished assembling most of the parts. I also made the spool holder. I found all the makeshift components from the tutorial's CAD assembly file and other online sources and made some of my own, like the makeshift power supply and motherboard. The makeshift parts helped in finding any errors in the dimensions of the 3D print CAD files. I made the motherboard and power supply into rectangular prisms showing its maximum occupying volume, especially as their actual designs are extremely complex and not necessary for the assembly file. Then I also found an open-source firmware config file for a SCARA 3D Printer, which we decided to use as the template for our printer too. We will configure the firmware specific to our robot arm once we get the parts. 
Then, we made the ReadMe file together and all the other small requirements, and now we are finally ready to submit!

Front view of the assembled printer:
<br>  <br>

Side view of the assembled printer:
<br> 
<br>
Isometric view of the assembled printer:
<br> 
<br>
Design for the spool:
<br> 
<br>
Design for the makeshift screen:
<br> 
<br>
Updated Base Plate with the mount for the screen:
<br> 
<br>
Isometric view of the Makeshift Extruder:
<br> 
<br>
Note: We ended up changing the colors in the end to make it all 1 color, for the updated screenshots with the new colour, check the Readme file.

# July 22 : Feedback and planning
## Hours spent : 2

After submitting our project, we got some feedback from Toby and decided to work on it asap. First, I broke down the feedback into some steps or guidelines for reference:


Though we realized backlash would be an issue from the start, we decided to try and minimize it after Toby's comment. Shielded wires also seemed necessary so we decided to add that. I realized I should recalculate the final torques, which I will do tomorrow. 

Tomorrow, I'll also work on part sourcing and finding alternatives and ways to cut down the budget a little so that we can potentially use better motors.

# July 23: Torques, Parts, etc.
## Hours spent: 3

Today, I calculated the torques from the masses Parth calculated. This table helps confirm that our current motors + gearboxes are capable enough to lift the arm.


But, to avoid backlash and compounding error, we had to eliminate as many gearboxes as possible, so we found Nema23 alternatives for the wrist section of the arm. Even if we wanted to remove gearboxes for the others, we couldn't as the gearboxes would still be needed but at least we tried reducing backlash should hopefully that counts for something. I also realized we could cut filament from the budget as I have some 3D pen filament that could be used for testing and save some money there. Here's some parts I found today (but that haven't been added to the BOM):


We will update the CAD tmrw and hopefully resubmit everything soon.

# July 24: CAD
## Hours spent: 1

Today, we changed the sizes for the motor compartments in the wrist section and update the sizes for the screw holes. I worked on Wrist Pitch Mount while Parth worked on Wrist Roll. Here's what I ended up making:


I also realized there were issues with the motor horn for the Wrist Pitch, so I decided to fix those tomorrow.

# July 25: CAD and updating Github
## Hours spent: 3

Today, I decided to finish the assembly file, group all the components in their final positions together and make sure everything was aligned to polish it. I also added the new Nema23 motors to the assembly.  


I also fixed the Wrist Pitch section by recreating the Wrist Pitch End


I finalized the BOM and uploaded it to Github. To reply to Toby, I will further explain the belt mechanism, how theres a gap for double layering and increasing the tension. I will talk about ways plan to connect the wires, by sending them through some of the extra holes we made throughout the arm and using adhesive cable ties to make sure they're all in place. With this final update, we should hopefully be ready to get approved.

# September 11: Assembly
## Hours spent: 3

It took us way too long to get all the parts from Ali Express and to get the 3D printed parts. Also, school started so we couldn't really work on this for long periods of time but finally we started the assembly. We assembled the mechanical parts of the base. We realized 2 errors, firstly, the pulley wheels we ordered for the motors were not the right size. Secondly, the wires from the motor were on the side and the hole we designed for the wire was on the back, thus the motor did not fit in the Wrist Roll. We had to come up with a solution for these problems.

# September 13: Problem-Solving
## Hours spent: 2

After Alex's approval, we ordered new pulley wheels for the motors. Also, instead of waiting for the wrist roll to be reprinted, we just cut through the part to make a hole for the wires using a heated knife. This is a temporary fix so that we don't stop working and in the long-term, we'll reprint the part.

# September 16: More Assembly
## Hours spent: 3

We continued working on the assembly for the arm. We realized a couple more errors, such as the belt was not staying in place. The 3D printing was not precise enough for the belt and we tried taping it together but it didn't work. We're really stuck and trying to figure out how to get the belt to stay in place because it's crucial to our design. Moreover, another  3d printed part has a defect (size doesn't match). We need to solve these problems before we can make any further progress.

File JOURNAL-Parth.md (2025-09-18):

---
title: DUM-E Printer (A SCARA 3D Printer)
author: Parth Bhasin
description: A 5-axis robotic arm that can 3D Print (SCARA 3D printer) 
created_at: 2025-07-02
total_hrs_submitted: 92
total_hrs_worked: 104
---
 (Note: we modified a few things after submission and updated the CAD files and Readme which is why the submitted hours and total hours do not match)
 
# July 1: Brainstorming
## Hours Spent: 4
After multiple options were discussed, me and my partner (Sujay Golla) decided to build a SCARA 3D printer. We discussed what features we want our 3D printer to have and looked for inspiration from other 3D Printers.

A feature I want to include is info display screen (temperature, progress, etc.)

# July 3: Reading Tutorials
## Hours Spent: 10

I browsed the internet to find all the 3D printer or robotic arm tutorials I could find. I also used Hackclub highway 3D printer guides. I watched/read tutorials basically to understand the project better. 
I started working on the BOM to get a better idea of the dimensions of the parts and electronics to start working on the wiring diagrams and the CAD. We referred to the following tutorials to get a better sense of how our printer will work:
- https://www.drdflo.com/pages/Guides/How-to-Build-a-3D-Printer/FFF.html
- https://roboticworx.io/blogs/projects/build-a-5-axis-industrial-grade-robotic-arm-that-learns-how-to

Then, we came up with a rough idea for the BOM:
- We can't decide between Servos or stepper motors yet
- Belt, pulley wheels, bearings, wires, jumper wires
- Motherboard (preferably with Marlin 2.0)
- Extruder stuff
- Power supply
- Filament (for the 3D printed shell of the arm)

We plan to finish the BOM together while working on wiring diagrams and CAD simultaneously to make sure we include all of the components needed to make the project.

Here is the first page of tutorials doc I made:


# July 7: Working on BOM and the wiring diagram
## Hours Spent: 6
Today, we worked on finalizing our BOM by sourcing parts from AliExpress and Amazon (wherever they are cheaper) by referencing the same tutorials, picking all the smaller items like wires and tools. I sourced half the parts and my teammate did the rest. For now, our BOM looks like:


Hopefully, we can get designing in a few days!

# July 9: Starting to make CAD Files
## Hours Spent: 10

Today, I started working on the CAD files for our printer. I made accounts for Onshape. The reason I chose Onshape is because it allows real-time collaboration online, which is a great feature for people working in teams, and it is also one of the easiest softwares for beginners. I spent a couple hours familiarizing myself with the software by looking at online tutorials and creating mini-projects on Onshape. Then we started discussing about our 3D printer. We narrowed down a couple features for the 3D printer, like deciding between whether we want to split the load by adding another motor and using a smaller gearbox for each or use one stepper motor with a large gearbox. We also discussed if we want to use screws to join the parts or make snap-fit joints. I want to learn more about Onshape and create a list of parts and think about how they will all fit together before diving straight into designing the printer.

# July 10-15: Learning Onshape
## Hours Spent: 8

I tried to start working on the printer but ran into a lot of issues mainly because we had never used Onshape and weren't familiar with the features and tools. I spent a few days explore different tools and creating mini projects on Onshape. I didn't get started on the actual printer because of some other personal commitments.

# July 16: 3D Printed Sections list + CAD
## Hours Spent: 6

Today, I actually started designing! I created the base plate using circle sketches and extrusions. I am really enjoying working with Onshape!
The first part looks like this so far:


Me and my teammate decided to start from the opposite ends. So, I am working on the Base and working my way upwards while he startes from te top and works downward. However, the Base plate and the Base are both complex parts so let's see how many parts I can actually end up making. Moreover, while we are inspired by the tutorial, we are referencing it for the dimensions of bolts and general dimensions of the arm, just so we can go off of something. The actual arm will look different and of course, the functionality will be much more complex and unique. 

# July 17: CAD + BOM
## Hours Spent: 3

Continued working on the base plate. Learnt a bunch of new features. Most importantly, I leart how to sketch on a curved surface which was kinda tricky for a beginner like me.



The BOM looks like this now:


# July 18: CAD
## Hours Spent: 5

Continued working on the base plate. This is how it currently looks:


Learnt to use the circular pattern tool!

# July 19: CAD
## Hours Spent: 12

I started working on the base today. It was so frustrating to make the ridges and I had to make it in 5 different draft files before it finally worked. However, my partner and I made a lot of progress in the CAD today, possibly over 70% done the entire arm. From the wrist end of the arm, we finished the entirety of J2 and worked on 70% of J1. A lot of parts for J1 are going to be similar to J2, so we hope this will be finished even quicker.

One of the errors I could not fix for a long time:



But then I fixed it:



And then I circle patterned it:



And it finally works:



# July 20: CAD
## Hours Spent: 14

I panicked today because I realized that AliExpress might take too much time to ship the parts and wanted to submit today. I and my teammate decided to lock in and we finished designing all the parts. Then we started assembling all the parts in the assembly file. There were so many errors and dimensions issues that we had to go back and redo a bunch of parts. I fixed the J1 Base file that my teammate made because for some reason, the holes for the screws weren't aligned properly. The entire process took way longer than we expected and we had to pull an all-nighter. Unfortunately we could not submit because we still had a bunch of stuff left to do. We must submit this tomorrow tho!



# July 21: CAD
## Hours Spent: 14

We finished assembling most of the parts. Next, we had to add a bunch of makeshift parts in the assembly file. These included the bearings, motors, screen, power source, motherboard etc. Basically, these are the parts we are not going to 3D print, but instead buy. For instance, we would buy the motors, not 3D print the motors. But, in order to be 100% precise in the assembly file, we created makeshift designs for all these parts so that the dimensions make sense in the assembly. I personally made the makeshift bearing, makeshift screen and one of the makeshift motors. This was an interesting process because I learnt a few new tools like the Boolean, Union, Split and Transform tools. I designed a rough sketch for the extruder and added that to the assembly file for accuracy. Then my teammate found an open-source file for a SCARA 3D Printer's firmware which we decided to use as the template for our printer too. The firmware is going to be essentially the same because it is also a SCARA printer and uses the same SCARA kinematics. We will configure the firmware specific to our robot arm once we get the parts. Then, we made a ReadMe file for our printer and now we are finally ready to submit!

Front view of the assembled printer:
<br>  <br>

Side view of the assembled printer:
<br> 
<br>
Isometric view of the assembled printer:
<br> 
<br>
Design for the spool:
<br> 
<br>
Design for the makeshift screen:
<br> 
<br>
Updated Base Plate with the mount for the screen:
<br> 
<br>
Isometric view of the Makeshift Extruder:
<br> 
<br>
Note: We ended up changing the colors in the end to make it all 1 color, for the updated screenshots with the new colour, check the Readme file.

# July 22: Working on Feedback
## Hours Spent: 1

We received feedback from a peer on our submission today and we are really grateful for that. We are looking to improve our DUM-E Printer and this feedback was really useful. Even though my teammate Sujay had calculated all the torque values and chosen the motors appropriately, he had used approximate values for the mass of the parts because we didn't have an exact tutorial to refer to. However, now that we do have the 3D Printed model, I assigned materials to all the parts and collected their masses. I did the calculations using the density of PLA which is 0.001 g/mm^3. PLA is one of the most common 3D printer filaments. Other alternatives incluse ABS and Polycarbonate which have very similar density, thus the mass would not change significantly. Now Sujay is going to rerun the torque calculations tomorrow. In the meantime, I researched more about the other feedback our peer gave us.

Here's the table which contains all the mass values for our printer:


# July 24: Updating motor compartments
## Hours spent: 1

We decided to switch 2 of our motors to NEMA-23 without gearboxes to prevent backlash. Since the NEMA-23 motors are bigger, we had to change the dimensions of our motor compartments. Changed the CAD diagrams to acommodate bigger motors.

# July 25: Filleting
## Hours spent: 2

Based on the feedback, I filleted the 3D printed parts today. Then, I also created an exploded diagram of the assembly file. The purpose of the exploded diagram is for the reviewers to be able to see all the makeshift bearings and the makeshift motors we are using. Additionally, we modified a few parts' dimensions. For example, we increased the length of the Wrist Pitch end because it was colliding with other parts earlier. I also increased the thickness of the screen mount because it was 2 mm earlier and I felt that might be too brittle. My teammate Sujay was working on an updated BOM since we decided to switch 2 of our motors to NEMA-23 without gearboxes to prevent backlash. We added the shielded wires, motors and the M5 bolts in the BOM. He also changed a couple parts and we decided to not use the Wrist Pitch Motor Horn because it would not have held the motor in place so he edited the parts to create a new mechanism to hold the motor in place.

Here are some of the filleted parts and the exploded diagrams:









# September 11: Assembly
## Hours spent: 3

It took us way too long to get all the parts from Ali Express and to get the 3D printed parts. Also, school started so we couldn't really work on this for long periods of time but finally we started the assembly. We assembled the mechanical parts of the base. We realized 2 errors, firstly, the pulley wheels we ordered for the motors were not the right size. Secondly, the wires from the motor were on the side and the hole we designed for the wire was on the back, thus the motor did not fit in the Wrist Roll. We had to come up with a solution for these problems.

# September 13: Problem-Solving
## Hours spent: 2

After Alex's approval, we ordered new pulley wheels for the motors. Also, instead of waiting for the wrist roll to be reprinted, we just cut through the part to make a hole for the wires using a heated knife. This is a temporary fix so that we don't stop working and in the long-term, we'll reprint the part.

# September 16: More Assembly
## Hours spent: 3

We continued working on the assembly for the arm. We realized a couple more errors, such as the belt was not staying in place. The 3D printing was not precise enough for the belt and we tried taping it together but it didn't work. We're really stuck and trying to figure out how to get the belt to stay in place because it's crucial to our design. Moreover, another  3d printed part has a defect (size doesn't match). We need to solve these problems before we can make any further progress.

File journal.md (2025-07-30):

@PB Journal: https://github.com/ParthB21/DUM-E-Printer/blob/main/JOURNAL-Parth.md
@Sujay Journal: https://github.com/ParthB21/DUM-E-Printer/blob/main/JOURNAL-Sujay.md

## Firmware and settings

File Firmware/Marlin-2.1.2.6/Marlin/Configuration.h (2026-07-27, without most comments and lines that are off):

#pragma once
#define CONFIGURATION_H_VERSION 02010206
#define STRING_CONFIG_H_AUTHOR "(none, default config)" // Who made the changes.
#define SHOW_BOOTSCREEN
  #define MOTHERBOARD BOARD_MKS_ROBIN_NANO_V3_1
#define DUME_ARTICULATED_ARM
#define SERIAL_PORT -1
#define BAUDRATE 115200
#define CUSTOM_MACHINE_NAME "DUM-E"
#define X_DRIVER_TYPE  TMC2209
#define Y_DRIVER_TYPE  TMC2209
#define Z_DRIVER_TYPE  TMC2209
#define I_DRIVER_TYPE  TMC2209  // Wrist roll on physical E0 socket (DUME_ARTICULATED_ARM)
#define E0_DRIVER_TYPE TMC2209  // Filament extruder on physical E1 socket
  #define AXIS4_NAME 'A' // :['A', 'B', 'C', 'U', 'V', 'W']
  #define AXIS4_ROTATES
#define EXTRUDERS 1
#define DEFAULT_NOMINAL_FILAMENT_DIA 1.75
#define TEMP_SENSOR_0 1
#define TEMP_SENSOR_1 0
#define TEMP_SENSOR_2 0
#define TEMP_SENSOR_3 0
#define TEMP_SENSOR_4 0
#define TEMP_SENSOR_5 0
#define TEMP_SENSOR_6 0
#define TEMP_SENSOR_7 0
#define TEMP_SENSOR_BED 0
#define TEMP_SENSOR_PROBE 0
#define TEMP_SENSOR_CHAMBER 0
#define TEMP_SENSOR_COOLER 0
#define TEMP_SENSOR_BOARD 0
#define TEMP_SENSOR_REDUNDANT 0
#define DUMMY_THERMISTOR_998_VALUE  25
#define DUMMY_THERMISTOR_999_VALUE 100
#if TEMP_SENSOR_IS_MAX_TC(0)
  #define MAX31865_SENSOR_OHMS_0      100 // (Ω) Typically 100 or 1000 (PT100 or PT1000)
  #define MAX31865_CALIBRATION_OHMS_0 430 // (Ω) Typically 430 for Adafruit PT100; 4300 for Adafruit PT1000
#endif
#if TEMP_SENSOR_IS_MAX_TC(1)
  #define MAX31865_SENSOR_OHMS_1      100
  #define MAX31865_CALIBRATION_OHMS_1 430
#endif
#if TEMP_SENSOR_IS_MAX_TC(2)
  #define MAX31865_SENSOR_OHMS_2      100
  #define MAX31865_CALIBRATION_OHMS_2 430
#endif
#if HAS_E_TEMP_SENSOR
  #define TEMP_RESIDENCY_TIME         10  // (seconds) Time to wait for hotend to "settle" in M109
  #define TEMP_WINDOW                  1  // (°C) Temperature proximity for the "temperature reached" timer
  #define TEMP_HYSTERESIS              3  // (°C) Temperature proximity considered "close enough" to the target
#endif
#if TEMP_SENSOR_BED
  #define TEMP_BED_RESIDENCY_TIME     10  // (seconds) Time to wait for bed to "settle" in M190
  #define TEMP_BED_WINDOW              1  // (°C) Temperature proximity for the "temperature reached" timer
  #define TEMP_BED_HYSTERESIS          3  // (°C) Temperature proximity considered "close enough" to the target
#endif
#if TEMP_SENSOR_CHAMBER
  #define TEMP_CHAMBER_RESIDENCY_TIME 10  // (seconds) Time to wait for chamber to "settle" in M191
  #define TEMP_CHAMBER_WINDOW          1  // (°C) Temperature proximity for the "temperature reached" timer
  #define TEMP_CHAMBER_HYSTERESIS      3  // (°C) Temperature proximity considered "close enough" to the target
#endif
#if TEMP_SENSOR_REDUNDANT
  #define TEMP_SENSOR_REDUNDANT_SOURCE    E1  // The sensor that will provide the redundant reading.
  #define TEMP_SENSOR_REDUNDANT_TARGET    E0  // The sensor that we are providing a redundant reading for.
  #define TEMP_SENSOR_REDUNDANT_MAX_DIFF  10  // (°C) Temperature difference that will trigger a print abort.
#endif
#define HEATER_0_MINTEMP   5
#define HEATER_1_MINTEMP   5
#define HEATER_2_MINTEMP   5
#define HEATER_3_MINTEMP   5
#define HEATER_4_MINTEMP   5
#define HEATER_5_MINTEMP   5
#define HEATER_6_MINTEMP   5
#define HEATER_7_MINTEMP   5
#define BED_MINTEMP        5
#define CHAMBER_MINTEMP    5
#define HEATER_0_MAXTEMP 275
#define HEATER_1_MAXTEMP 275
#define HEATER_2_MAXTEMP 275
#define HEATER_3_MAXTEMP 275
#define HEATER_4_MAXTEMP 275
#define HEATER_5_MAXTEMP 275
#define HEATER_6_MAXTEMP 275
#define HEATER_7_MAXTEMP 275
#define BED_MAXTEMP      150
#define CHAMBER_MAXTEMP  60
#define HOTEND_OVERSHOOT 15   // (°C) Forbid temperatures over MAXTEMP - OVERSHOOT
#define BED_OVERSHOOT    10   // (°C) Forbid temperatures over MAXTEMP - OVERSHOOT
#define COOLER_OVERSHOOT  2   // (°C) Forbid temperatures closer than OVERSHOOT
#define PIDTEMP           // See the PID Tuning Guide at https://reprap.org/wiki/PID_Tuning
#define PID_MAX  255      // Limit hotend current while PID is active (see PID_FUNCTIONAL_RANGE below); 255=full current
#define PID_K1     0.95   // Smoothing factor within any PID loop
    #define DEFAULT_KP  22.20
    #define DEFAULT_KI   1.08
    #define DEFAULT_KD 114.00
#define MAX_BED_POWER 255 // limits duty cycle to bed; 255=full current
#define MAX_CHAMBER_POWER 255 // limits duty cycle to chamber heater; 255=full current
  #define PID_FUNCTIONAL_RANGE 10 // If the temperature difference between the target temperature and the actual temperature
#define PREVENT_COLD_EXTRUSION
#define EXTRUDE_MINTEMP 170
#define PREVENT_LENGTHY_EXTRUDE
#define EXTRUDE_MAXLENGTH 200
#define THERMAL_PROTECTION_HOTENDS // Enable thermal protection for all extruders
#define THERMAL_PROTECTION_BED     // Enable thermal protection for the heated bed
#define THERMAL_PROTECTION_CHAMBER // Enable thermal protection for the heated chamber
#define THERMAL_PROTECTION_COOLER  // Enable thermal protection for the laser cooling
#define USE_XMIN_PLUG
#define USE_YMIN_PLUG
#define USE_ZMIN_PLUG
#define USE_IMIN_PLUG   // Wrist roll (A) on Z+ / E0_DIAG connector
#define ENDSTOPPULLUPS
#define X_MIN_ENDSTOP_INVERTING false // Set to true to invert the logic of the endstop.
#define Y_MIN_ENDSTOP_INVERTING false // Set to true to invert the logic of the endstop.
#define Z_MIN_ENDSTOP_INVERTING false // Set to true to invert the logic of the endstop.
#define I_MIN_ENDSTOP_INVERTING false // Set to true to invert the logic of the endstop.
#define J_MIN_ENDSTOP_INVERTING false // Set to true to invert the logic of the endstop.
#define K_MIN_ENDSTOP_INVERTING false // Set to true to invert the logic of the endstop.
#define U_MIN_ENDSTOP_INVERTING false // Set to true to invert the logic of the endstop.
#define V_MIN_ENDSTOP_INVERTING false // Set to true to invert the logic of the endstop.
#define W_MIN_ENDSTOP_INVERTING false // Set to true to invert the logic of the endstop.
#define X_MAX_ENDSTOP_INVERTING false // Set to true to invert the logic of the endstop.
#define Y_MAX_ENDSTOP_INVERTING false // Set to true to invert the logic of the endstop.
#define Z_MAX_ENDSTOP_INVERTING false // Set to true to invert the logic of the endstop.
#define I_MAX_ENDSTOP_INVERTING false // Set to true to invert the logic of the endstop.
#define J_MAX_ENDSTOP_INVERTING false // Set to true to invert the logic of the endstop.
#define K_MAX_ENDSTOP_INVERTING false // Set to true to invert the logic of the endstop.
#define U_MAX_ENDSTOP_INVERTING false // Set to true to invert the logic of the endstop.
#define V_MAX_ENDSTOP_INVERTING false // Set to true to invert the logic of the endstop.
#define W_MAX_ENDSTOP_INVERTING false // Set to true to invert the logic of the endstop.
#define Z_MIN_PROBE_ENDSTOP_INVERTING false // Set to true to invert the logic of the probe.
#define DEFAULT_AXIS_STEPS_PER_UNIT   { 124.44, 8.89, 453.33, 8.89, 95 }
#define DEFAULT_MAX_FEEDRATE          { 30, 30, 20, 30, 25 }
#define DEFAULT_MAX_ACCELERATION      { 80, 80, 60, 80, 500 }
#define DEFAULT_ACCELERATION          80      // X, Y, Z and E acceleration for printing moves
#define DEFAULT_RETRACT_ACCELERATION  500     // E acceleration for retracts
#define DEFAULT_TRAVEL_ACCELERATION   80      // X, Y, Z acceleration for travel (non printing) moves
#define DEFAULT_EJERK    5.0  // May be used by Linear Advance
  #define JUNCTION_DEVIATION_MM 0.013 // (mm) Distance from real junction edge
  #define JD_HANDLE_SMALL_SEGMENTS    // Use curvature estimation instead of just the junction angle
#define S_CURVE_ACCELERATION
#define Z_MIN_PROBE_USES_Z_MIN_ENDSTOP_PIN
#define NOZZLE_TO_PROBE_OFFSET { 10, 10, 0 }
#define PROBING_MARGIN 10
#define XY_PROBE_FEEDRATE (133*60)
#define Z_PROBE_FEEDRATE_FAST (4*60)
#define Z_PROBE_FEEDRATE_SLOW (Z_PROBE_FEEDRATE_FAST / 2)
#define Z_CLEARANCE_DEPLOY_PROBE   10 // (mm) Z Clearance for Deploy/Stow
#define Z_CLEARANCE_BETWEEN_PROBES  5 // (mm) Z Clearance between probe points
#define Z_CLEARANCE_MULTI_PROBE     5 // (mm) Z Clearance between multiple probes
#define Z_PROBE_LOW_POINT          -2 // (mm) Farthest distance below the trigger-point to go before stopping
#define Z_PROBE_OFFSET_RANGE_MIN -20
#define Z_PROBE_OFFSET_RANGE_MAX 20
#define X_ENABLE_ON 0
#define Y_ENABLE_ON 0
#define Z_ENABLE_ON 0
#define E_ENABLE_ON 0 // For all extruders
#define I_ENABLE_ON 0 // Wrist roll (A)
#define DISABLE_OTHER_EXTRUDERS   // Keep only the active extruder enabled
#define INVERT_X_DIR false
#define INVERT_Y_DIR false
#define INVERT_Z_DIR false
#define INVERT_I_DIR false
#define INVERT_E0_DIR false
#define INVERT_E1_DIR false
#define INVERT_E2_DIR false
#define INVERT_E3_DIR false
#define INVERT_E4_DIR false
#define INVERT_E5_DIR false
#define INVERT_E6_DIR false
#define INVERT_E7_DIR false
#define X_HOME_DIR -1
#define Y_HOME_DIR -1
#define Z_HOME_DIR -1
#define I_HOME_DIR -1
#define X_BED_SIZE 360
#define Y_BED_SIZE 180
#define X_MIN_POS -180
#define Y_MIN_POS -90
#define Z_MIN_POS -90
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

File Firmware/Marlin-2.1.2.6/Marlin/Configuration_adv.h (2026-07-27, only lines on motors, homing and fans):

#define E0_AUTO_FAN_PIN -1
#define E1_AUTO_FAN_PIN -1
#define E2_AUTO_FAN_PIN -1
#define E3_AUTO_FAN_PIN -1
#define E4_AUTO_FAN_PIN -1
#define E5_AUTO_FAN_PIN -1
#define E6_AUTO_FAN_PIN -1
#define E7_AUTO_FAN_PIN -1
#define CHAMBER_AUTO_FAN_PIN -1
#define COOLER_AUTO_FAN_PIN -1
#define HOMING_BUMP_MM      { 5, 5, 2, 5 }    // X Y Z I (° for joints)
#define HOMING_BUMP_DIVISOR { 2, 2, 4, 2 }    // Re-Bump Speed Divisor (Divides the Homing Feedrate)
#define MICROSTEP_MODES { 16, 16, 16, 16, 16, 16 } // [1,2,4,8,16]
    #define X_CURRENT       800        // (mA) RMS current. Multiply by 1.414 for peak current.
    #define X_CURRENT_HOME  X_CURRENT  // (mA) RMS current for homing. (Typically lower than *_CURRENT.)
    #define X_MICROSTEPS     16        // 0..256
    #define Y_CURRENT      1000
    #define Y_CURRENT_HOME  Y_CURRENT
    #define Y_MICROSTEPS     16
    #define Z_CURRENT       800
    #define Z_CURRENT_HOME  Z_CURRENT
    #define Z_MICROSTEPS     16
    #define I_CURRENT     1000
    #define I_CURRENT_HOME I_CURRENT
    #define I_MICROSTEPS    16
    #define E0_CURRENT      700
    #define E0_MICROSTEPS    16
  #define X_HYBRID_THRESHOLD     100  // [mm/s]
  #define X2_HYBRID_THRESHOLD    100
  #define Y_HYBRID_THRESHOLD     100
  #define Y2_HYBRID_THRESHOLD    100
  #define Z_HYBRID_THRESHOLD       3
  #define Z2_HYBRID_THRESHOLD      3
  #define Z3_HYBRID_THRESHOLD      3
  #define Z4_HYBRID_THRESHOLD      3
  #define I_HYBRID_THRESHOLD       3  // [linear=mm/s, rotational=°/s]
  #define J_HYBRID_THRESHOLD       3  // [linear=mm/s, rotational=°/s]
  #define K_HYBRID_THRESHOLD       3  // [linear=mm/s, rotational=°/s]
  #define U_HYBRID_THRESHOLD       3  // [mm/s]
  #define V_HYBRID_THRESHOLD       3
  #define W_HYBRID_THRESHOLD       3
  #define E0_HYBRID_THRESHOLD     30
  #define E1_HYBRID_THRESHOLD     30
  #define E2_HYBRID_THRESHOLD     30
  #define E3_HYBRID_THRESHOLD     30
  #define E4_HYBRID_THRESHOLD     30
  #define E5_HYBRID_THRESHOLD     30
  #define E6_HYBRID_THRESHOLD     30
  #define E7_HYBRID_THRESHOLD     30

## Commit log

2025-07-22 Uploading CAD Files
    [Base.step, Bottom Base - Base Plate.step, J1 Base Mount.step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]
2025-07-22 Uploading Firmware
    [Configuration.h]
2025-07-22 Updated BOM
    [BOM - SCARA3D - Sheet2.csv]
2025-07-22 Reuploading final CAD
    [Extruder.step, J1 Base Mount.step, J1 Base New.step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]
2025-07-22 Adding the base and the base plate
    [Base Plate.step, Base.step]
2025-07-22 Rename J1 Base New.step to J1 Base.step
    [J1 Base.step]
2025-07-22 Update and rename BOM - SCARA3D - Sheet2.csv to BOM.csv
    [BOM.csv]
2025-07-22 Final BOM
    [BOM - Sheet2.csv]
2025-07-22 Update and rename BOM - Sheet2.csv to BOM.csv
    [BOM.csv]
2025-07-22 Uploading wiring diagram
2025-07-22 Adding taxes to BOM
    [BOM.csv]
2025-07-25 Updating BOM
    [BOM.csv]
2025-07-25 Updating BOM (fixing a column)
    [BOM.csv]
2025-12-10 Updating some parts
    [J1.step, Wrist Pitch mount.step]
2026-07-27 Add demo link to README for DUM-E Printer
    Added a demo link for the DUM-E Printer project.
2026-07-27 Change demo link in README.md
    Updated demo link to GitHub assets for DUM-E Printer.
2026-07-27 Add latest DUM-E Marlin firmware, bring-up guide, and keyboard jog demo under Firmware.
    [Configuration.h, Configuration_adv.h, esp32.csv]

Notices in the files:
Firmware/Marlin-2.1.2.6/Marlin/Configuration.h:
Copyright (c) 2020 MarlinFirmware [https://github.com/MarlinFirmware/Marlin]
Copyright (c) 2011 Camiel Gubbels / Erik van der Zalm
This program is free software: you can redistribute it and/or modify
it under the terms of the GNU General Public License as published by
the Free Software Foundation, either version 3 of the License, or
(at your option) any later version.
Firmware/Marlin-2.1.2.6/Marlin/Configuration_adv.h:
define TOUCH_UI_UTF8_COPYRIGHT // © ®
